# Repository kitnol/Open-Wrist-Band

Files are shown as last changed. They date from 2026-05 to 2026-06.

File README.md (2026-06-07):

# Open-Wrist-Band
Open-wrist-Band it is an open source project which created a wrist band that can measure various physiological parameters. The project features hardware and software deign. Main features:
- Photoplethysmography sensor (PPG)
- Electro Dermal Activity sensor (EDA)
- Internal Measurement Unit sensor (IMU)
- Examples of signal processing  algorithims

## File structure
Project is devided into two folders hardware and software consecutively.  
The hardware folder contains all of the 3D models and PCB design files.  
The software folder contains the scripts for the desktop sofware and ZephyrOS nRF SDK code for the wristband device running on nRF 52833.  
More features and how to get the device set up are described in detail in the individual README.md files within each folder.
## System overview
The system consists of a wearable wristband and a companion desktop application, interconnected via a USB interface
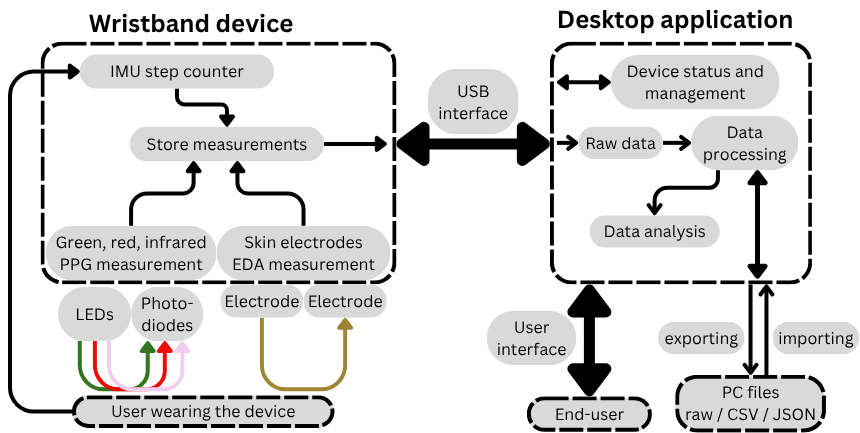
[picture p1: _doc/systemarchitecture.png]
System overview
  
The wristband measures and saves PPG, EDA and steps data in the onboard memory throughout the week, which is then offloaded to the desktop using a USB-C cable. The measurement parameters (frequency, LED brightness...) can be configured within the AS7058 chip driver. The captured data is then parsed and can be analysed using python notebooks.

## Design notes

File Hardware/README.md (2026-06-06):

# Hardware Documentation

## Overview

Here is presented a documentation for hardware, mechanical and electronics parts. Here described hardware manufacturing, assembly process and testing.

## Table of Contents

1. [Specifications](#specifications)
2. [PCB](#pcb)
3. [Mechanical](#mechanical)
4. [Full assembly](#full-assembly)
5. [Testing & Validation](#testing--validation)
6. [Bill of Materials (BOM)](#bill-of-materials-bom)

## Specifications

| Parameter | Value | Notes |
|---|---|---|
| Dimensions | 46.3 x 34 x 16.9 mm| |
| Sensors |PPG, EDA, IMU| For hear rate, SpO2, stress measurements and step counting|
| Weight | 42 grams | Weight with the strap|
| Operating Voltage | 3.6-4.2V | From the battery |
| Current Consumption | 1mA | When PPG and EDA measurements are on |
| Wrist circumference | 150-240 mm | |
| Charging current | 100mA | |
| Battery capacity | 800mA | Smaller battery capacity can be used |

## PCB
### PCB ordering

In this section described ordering process of the PCB manufacturing from JLCPCB.

After uploading gerber zip archive form [`./PCB/Fabrication files/Gerber.zip`](https://github.com/kitnol/Open-Wrist-Band/blob/main/Hardware/PCB/Fabrication%20files/Gerber.zip) There is few key options needed to be selected for PCB to be manufactured correctly.

Necessary options:
- **Layers**: 4
- **PCB Thickness**: 1.6mm
- **Surface Finish**: LeadFree HASL
- **Outer Copper Weight**: 1oz
- **Inner Copper Weight** 0.5oz
- **Via Covering**: Epoxy Filled Capped 
- **Min via hole size/diameter**: 0.15mm/(0.25/0.3mm) 

Recommended options:
- **Product Type**: Medical
- **Electrical Test**: Flying Probe Fully Test

### PCB Assembly

You can choose between two methods for assembling the PCB:

- **Manual Assembly**: Order all components listed in the `BOM.csv` and assemble the board entirely on your own.

- **Partial Assembly by JLCPCB**: Upload both `BOM.csv` and `CPL.csv` to the JLCPCB website for automated assembly.

**Important Note**: Because they are not carried in the standard JLCPCB component library, you must purchase the following parts separately and solder them yourself:

- Flash Memory: IS25WP01GJ

- Power Management IC (PMIC): nPM1304

Depending on the time of order additional components may occasionally be out of stock at JLCPCB, requiring you to source and solder them manually as well.

## Mechanical 

### Enclosure manufacturing

The primary method for fabricating the enclosure is FDM 3D printing.

- **Material Selection**: PETG is the recommended choice, though PLA or any other hypoallergenic (skin-safe) plastic may be used.

- **Post-Processing**: After printing, sand the parts and apply a layer of filler-primer to smooth out the print lines.

**Important Safety Note**: Because this device comes into contact with the body, ensure that all selected plastics, primers, and finishes are non-allergenic and completely skin-safe once fully cured.

### Electrodes

The electrodes can be fabricated using either CNC machining or metal 3D printing, utilizing the 3D model found in `./3d models/Electrode.stl`.

- **Material**: Stainless Steel 316 (SS316) is required.

- **Surface Finish**: Because these electrodes come into direct contact with the skin, they must be polished to a smooth surface finish to prevent irritation.

After fabrication, spot-weld a nickel strip to each electrode (the enclosure features a dedicated cutout to accommodate this). These nickel strips provide a solderable surface, allowing you to connect a wire from the electrodes directly to the PCB.

### PPG window

For the PPG sensor to function correctly, it requires an unobstructed view of the skin while remaining protected from sweat and moisture. To achieve this, fabricate a small protective separator from a **0.5 mm thick sheet of transparent PET plastic or glass**. Installation Steps:
  
- **Cut the Window**: Cut a $11.4 \text{ mm} \times 12.4 \text{ mm}$ rectangle out of the transparent material.
  
- **Apply Adhesive**: Using a toothpick, carefully apply a small amount of superglue along the recessed rim of the enclosure's cutout. 
  **Caution**: Avoid getting any glue near the center of the cutout where it could obscure the LEDs or photodiodes.
  
- **Set the Window**: Place the transparent window into the cutout and apply light, steady finger pressure for 1 to 2 minutes to ensure a secure bond.

## Full assembly

Once all components have been sourced and manufactured, you can proceed with the final assembly.

**Important**: You must flash the firmware onto the MCU using a J-LINK debugger before assembling the hardware. Please refer to the flashing guide located in the [Software](https://github.com/kitnol/Open-Wrist-Band/tree/main/Software) folder before proceeding. Also remove the male pins for J-LINK after programming, future updates can be done via USB.

**Step 1: Install the Electrodes**

1. Gather the fully prepared electrodes (with nickel strips attached), the casing body, and the 3D-printed jig (Glue_support.stl).
   
2. Route the nickel strip through its designated cutout in the casing, apply superglue beneath the electrode, and press it firmly into position.
   
3. Use the Glue_support.stl jig to clamp the casing body and electrode securely in a vice.
   
4. Allow **10–20 minutes** for the glue to fully cure. Repeat this process separately for each electrode.

**Step 2: PCB Mounting & Wiring**

1. Seat the PCB into the casing body.
   
2. Solder lead wires onto the exposed electrode nickel strips.
   
3. Solder the opposite ends of these wires into holes 2 and 4 of the PCB (located on the side opposite the USB port, counting sequentially from the outer edge of the PCB).
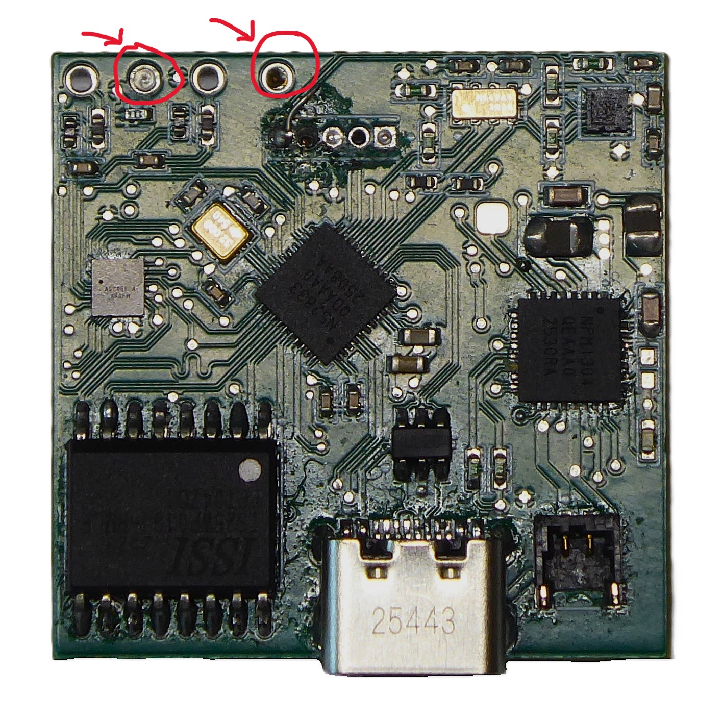
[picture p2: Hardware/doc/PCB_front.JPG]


**Step 3: Battery Installation & Final Closure**

1. Connect the battery, position it neatly on top of the PCB, and place the lid over the casing.

2. Caution: Double-check that no wires are pinched or trapped between the casing body and the lid.
   
3. Secure the enclosure using four M2 x 3mm screws to complete the assembly.

## Testing & Validation

### Hardware Testing
- [ ] Short circuits test
- [ ] Power test
- [ ] Charging test **(TODO)**

#### Short circuits test

Pre-Power Short Circuit Test

Once the PCB is fully assembled, you must test it for short circuits before applying power. Set your multimeter to continuity mode and check the continuity between the following points:

- **GND** and the **1.8V** line

- **GND** and the **2.4V** line

- **1.8V** line and the **2.4V** line

If the multimeter does not beep (indicating no continuity), it is safe to power on the PCB. If continuity is detected, a short circuit exists. <u>Do not apply power until you locate and resolve the source of the short.</u>

#### Power testing

Before programming, power the PCB via USB or battery and use a multimeter to measure the 1.8V and 2.4V lines. If the voltages are correct, it is safe to proceed with programming.

**Troubleshooting Guide:**

- **Voltages are too low**: Check the power input to ensure the board is receiving either 5V (USB) or 3.7V–4.2V (battery).

- **1.8V line is too high**: Immediately disconnect power. Verify that resistor R6 is 47 kΩ. Note that if this line exceeded 1.98V, the AS7058 component is likely damaged and must be replaced.

- **2.4V line is too high**: Power off the PCB immediately and verify that resistor R7 is 47 kΩ. Component damage is unlikely on this line, so no replacements should be necessary once the resistor issue is fixed.

## Bill of Materials (BOM)

### Mechanical BOM

| Part number | Description  | Quantity | Unit Price | Source |
|---|---|---|---|---|
| AM4885 | Li-Pol battery 800mAh, 3.7V, 622540 | 1 |€6.55 | [AM4885](https://ampul.eu/en/battery/6303-li-pol-battery-800mah-37v-622540) |
| ACHLR-02V-S | Battery connector | 1 | €0.13 | [ACHLR-02V-S](https://www.digikey.de/en/products/detail/jst-sales-america-inc/achlr-02v-s/5272191) |
| ASACHLSACHL28W152 | Battery wires | 1 | €0.98 | [ASACHLSACHL28W152](https://www.digikey.de/en/products/detail/jst-sales-america-inc/ASACHLSACHL28W152/8107430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) |
| M2 3mm | Screw for lid | 4 | €5.88 | [M2 3mm](https://dk.rs-online.com/web/p/maskinskruer/9141560) |
| PET 0.5mm | Plastic sheet | 1 | €7.5 | [PET 0.5mm](https://www.amazon.com/Plastic-Clarity-Resistant-Display-Packaging/dp/B0GJ6CKP9T?th=1) |

**Total Cost**: €38.68

### Electronics BOM
| Designator | Description | Footprint | JLCPCB Part | Quantity | Unit price ($) | Total cost ($) |
|---|---|-----|---|---|---|---|
| C1, C3, C4, C5, C6, C8, C10, C16, C21, C22, C32, C33, C34, C35 | 100nF | 0402 | C1525 | 14 | $0.0017 | $0.0238 |
| C2 | 10 µF | 0402 | C15525 | 1 | $0.0178 | $0.0178 |
| C7 | 1 µF | 0402 | C52923 | 1 | $0.0053 | $0.0053 |
| C9, C11, C14, C17, C25 | 1µF 40% 50V | 0603 | C15849 | 3 | $0.0156 | $0.0468 |
| C15, C19, C23, C24, C26 | 10 µF | 0603 | C19702 | 5 | $0.0149 | $0.0745 |
|  | 1 µF | 0603 | C15849 | 2 | $0.0108 | $0.0216 |
| C18 | 2.2 µF | 0603 | C49326366 | 1 | $0.0092 | $0.0184 |
| C20 | 100 pF | 0402 | C1546 | 1 | $0.0014 | $0.0014 |
| C27 | 4.7 µF | 0603 | C19666 | 1 | $0.0138 | $0.0138 |
| C28, C29, C30, C31 | 0.047 µF | 0402 | C82219 | 4 | $0.0024 | $0.0096 |
| C36, C37 | 12 pF | 0402 | C1547 | 2 | $0.0016 | $0.0032 |
| D1, D2 | SFH 7018A | SFH 7018 | C24570310 | 2 | $1.8124 | $3.6248 |
| D3, D4 | Blue LED | 0402 | C22355736 | 1 | $0.0087 | $0.0174 |
| D5, D6, D7, D8 | TVS DIODE | 0402 | C10676 | 4 | $0.0426 | $0.1704 |
| D9, D10, D11, D12 | SFH2705 | DFN175P2 | C6672359 | 4 | $1.7060 | $6.824 |
| J1 | USB-C Molex-2171790001 | SMD | C3197684 | 1 | $0.6895 | $0.6895 |
| J2 | Battery connector BM02B-ACHLKS | FP-BM02B | C594367 | 1 | $0.7975 |$0.7975 |
| J3 | M50-3530542 | Plugin,P=1.27mm| C6293302 | 1 | $0.3278 | $0.3278 |
| L1, L2 | CIGT201610LH2R2MNE | 0806 | C307626 | 2 | $0.1070 | $0.214 |
| R1, R2, R12, R13 | 5.1K | 0402 | C25905 | 4 | $0.0009 | $0.0036 |
| R3, R4, R5, R8, R11, R14, R19, R20, R21, R22, R23, R24, R25 | 10K | 0402 | C844452 | 17 | $0.0013 | $0.0221 |
| R6, R7 | 47K | 0402 | C25792 | 2 | $0.001 | $0.002 |
| R9, R10, R16, R17 | 100K | 0402 | C25741 | 4 | $0.0009 | $0.0036 | 
| R15, R26, R27, R28 | 4.7K | 0402 | C25900 | 4 | $0.001 | $0.004  |
| R18 | 1K | 0402 | C11702 | 1 | $0.001 | $0.001 |
| U1 | LIS2DS12TR | LGA-12(2x2) | C915682 | 1 | $2.0411 | $2.0411 |
| U2 | nRF52833 | QFN40_5X5 | C3007767 | 1 | $5.0552 | $5.0552 |
| U3 | NPM1304 | QFN32 | C49449665 | 1 | $4.3002 | $4.3002 | 
| U4 | RV-3028-C7 | FP-RV-3028-C7 | C3019759 | 1 | $2.2667 | $2.2667 |
| U5 | AS7058 | WLCSP-42(2.8x2.6) | C23782775 | 1 | $7.5763 | $7.5763 |
| U6 | IS25WP01GJ-RMLE-TY (128MB) | 16-SOIC | [DigiKey](https://www.digikey.de/en/products/detail/issi-integrated-silicon-solution-inc/IS25WP01GJ-RMLE-TY/29286651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) | 1 | $14.38360 | $14.38360 |
| U7 | USBLC6-2SC6 (ESD) | SOT-23-6 | C2827654 | 1 | $0.0410 | $0.0410 |
| Y1 | XYDCELNANF-32M | SMD2520-4P | C124330 | 1 | $0.3137 | $0.3137 |

**Total Cost**: $48.8926

---

**Last Updated**: 06-06-2026

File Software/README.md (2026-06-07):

## Folder structure
The code is split into two subfolders, embedded software and desktop software. The desktop software is written using python whereas the embedded software is written with C using ZephyrOS RTOS implementation.
## Device communication
The communication betweend the PC and the embedded device happens with UART over USB (USB CDC ACM) using ZephyrOS shell implementation. Custom commands are predefined in the embedded code to allow the desktop app to interface and configure the device. The connection happens in master-slave configuration where the PC (master) sends the commands and the device (slave) responds to the commands.
> **Table:** Defined commands for the interface, commands marked with (dbg) are meant for debugging only.

| Cmd | Subcommand | Behavior of MCU | Behavior of application |
| --- | --- | --- | --- |
| `rtc` | `get` | Send current RTC time to the application | Check if device time is correct, sync if it is not and warn user |
| `rtc` | `set y.m.d h:m:s` | Set received time from application to RTC | Send system time to MCU, tell user if time was set correctly |
| `as7058` | `start` | Start measuring data | Show device as measuring |
| `as7058` | `stop` | Stop measuring data | Show device as not measuring |
| `as7058` | `read` | Transmit current FIFO buffer to the app | (dbg) Show incoming FIFO bytes |
| `flash` | `ls` | List files | (dbg) Show files in the folder |
| `flash` | `info <path>` | Send file info at path | Asks for readings.bin, shows how much measured data there is |
| `flash` | `dump <path>` | Transmit raw binary data (bytes) of the file | Receive transmitted binary data and save them |
| `flash` | `hex <path>` | Send hex dump of the file | (dbg) Used to inspect files |
| `flash` | `rm <path>` | Delete the file at path | Triggered by clearing current measurements from device, tells user if completed |
| `config` | `getid` | Send configured ID | Show ID of the device |
| `config` | `setid <id>` | Set device ID to the received ID | User sets the ID, shows updated ID |
| `config` | `get` | Send current config on device | Show device config in UI |
| `config` | `set <bytes>` | Receive config and save it to memory | Set device config based on how the user cofigured it in UI config |
| `<any>`  | `<any>` | (dbg) Do action of the built-in command| (dbg) Send any of the built-in zephyros shell commands

### Connection
Upon connection the device opens two COM ports to the PC, one meant for the shell interface and the other one meant for the binary data flash dumps. Because the desktop application itself is currently not developed, separate standalone scripts are used for recieving the data dumps, while the shell interface is used manually by the user using a serial terminal e.g. AuTerm to configure the device and initiate the transfers.

## Setting up device to take measurements (Manually using shell)
To setup measurements after the device is successfully flashed we need to tell it to start measuring. This functionality remains to be implemented in the user interface to simplify the process.
#### Connecting the device
1. Open a serial terminal application (AuTerm is used in this case, but we can use any other) 
2. Connect the device using USB-C cable and find the COM ports corresponding to the device, there should be two new COM ports showing up. The ports will have random numbers as they are assigned by the PC.  
Ports showing up
3. Open one of the ports to the device, if nothing shows up it is the data transfer port. Close it and open the other port where the shell interface should show up.  
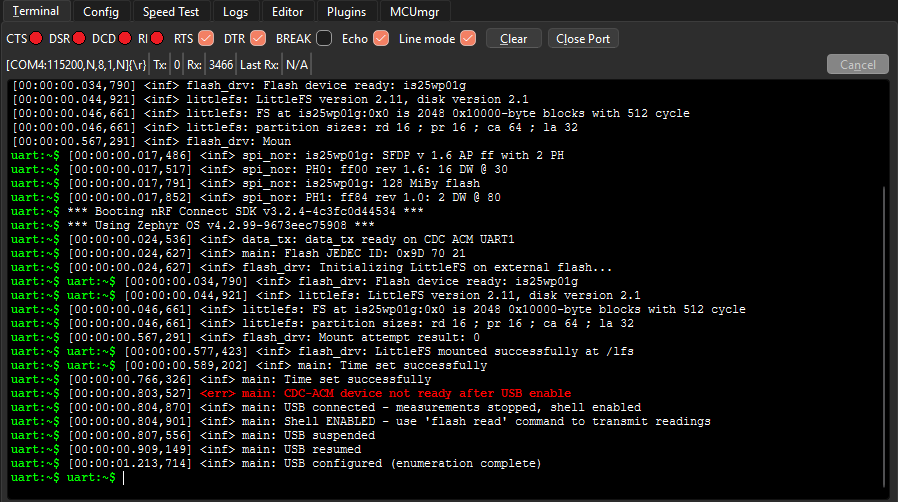
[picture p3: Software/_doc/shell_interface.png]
Shell interface

#### Starting measurement
4. We can see the onboard files using command `flash ls`. If we want to delete previous measurements so they do not mix up, we can use `flash rm /lfs/readings.bin`. Otherwise the measurements get appended at the end of the file
5. To start the measurement we send `as7058 start`. Depending on the measurement configuration we should start seeing LEDs blinking on the bottom of the device.  
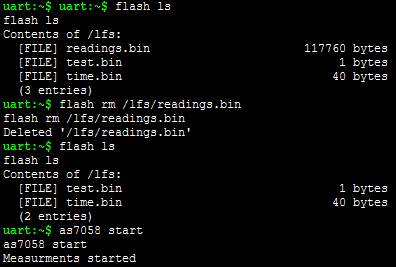
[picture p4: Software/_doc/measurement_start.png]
Starting measurement

6. In case we want to read the AS7058's FIFO memory while the measurements are running we can use `as7058 read` which will dump the current FIFO readings into the shell interface, instead of saving them into readings.bin. The device then continues taking measurements normally and would save the next FIFO memory measurements into the readings.bin file when the FIFO threshold is reached. It is important to note that this should be used for debugging only as it can create discontinuities in the readings.bin file.
## Stopping measurements and offloading the data (Manually using shell + scripts)
We begin with the same steps for connecting the device as previously.
### Stopping measurement
4. We stop the measurements by sending `as7058 stop`
5. We can see the size of collected measuremnts by doing `flash ls` where it shows the number of bytes  
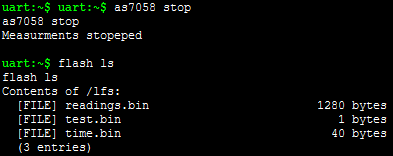
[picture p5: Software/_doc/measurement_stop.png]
Stopping measurement

### Offloading data
6. We initiate the offloading by sending shell command `flash dump /lfs/readings.bin` Then either by using a second serial terminal or by using the script data_receive.py we can capture the incomming transmission. The transmission is blocking so the data will wait for the port to be opened and won't be lost if we initiate the transmission without having the second port open first. From the command we can see the number of packets and number of bytes of the incoming transmission.  

#### Using second serial terminal
7. We initiate the connection on the second COM port shown by the device. We can see the incoming data captured in the terminal. If possible we can then export the data from the terminal.  
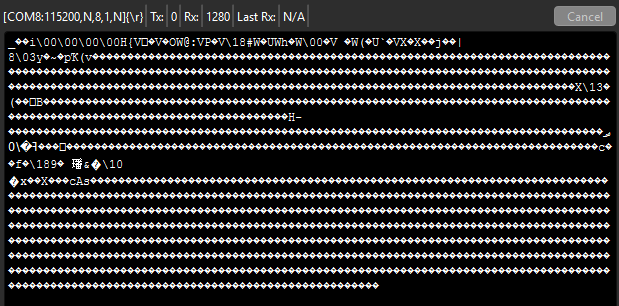
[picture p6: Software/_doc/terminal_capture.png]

#### Using the data_receive.py script
7. We open the receiving script. Modify the number of packets based on the output of the flash dump command and change the COM port to the second COM port of the device. We can also modify the desired file name.  
Receiving script
8. We can see the transmission happening and the data being saved in the .bin file.  
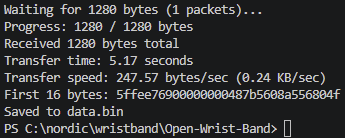
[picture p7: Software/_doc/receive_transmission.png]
Received transission


## To be implemented:
This is how it was envisioned that the device-application connection would interact, with a flowchart describing the behavior upon USB connection. This remains to be implemented from the desktop application side.

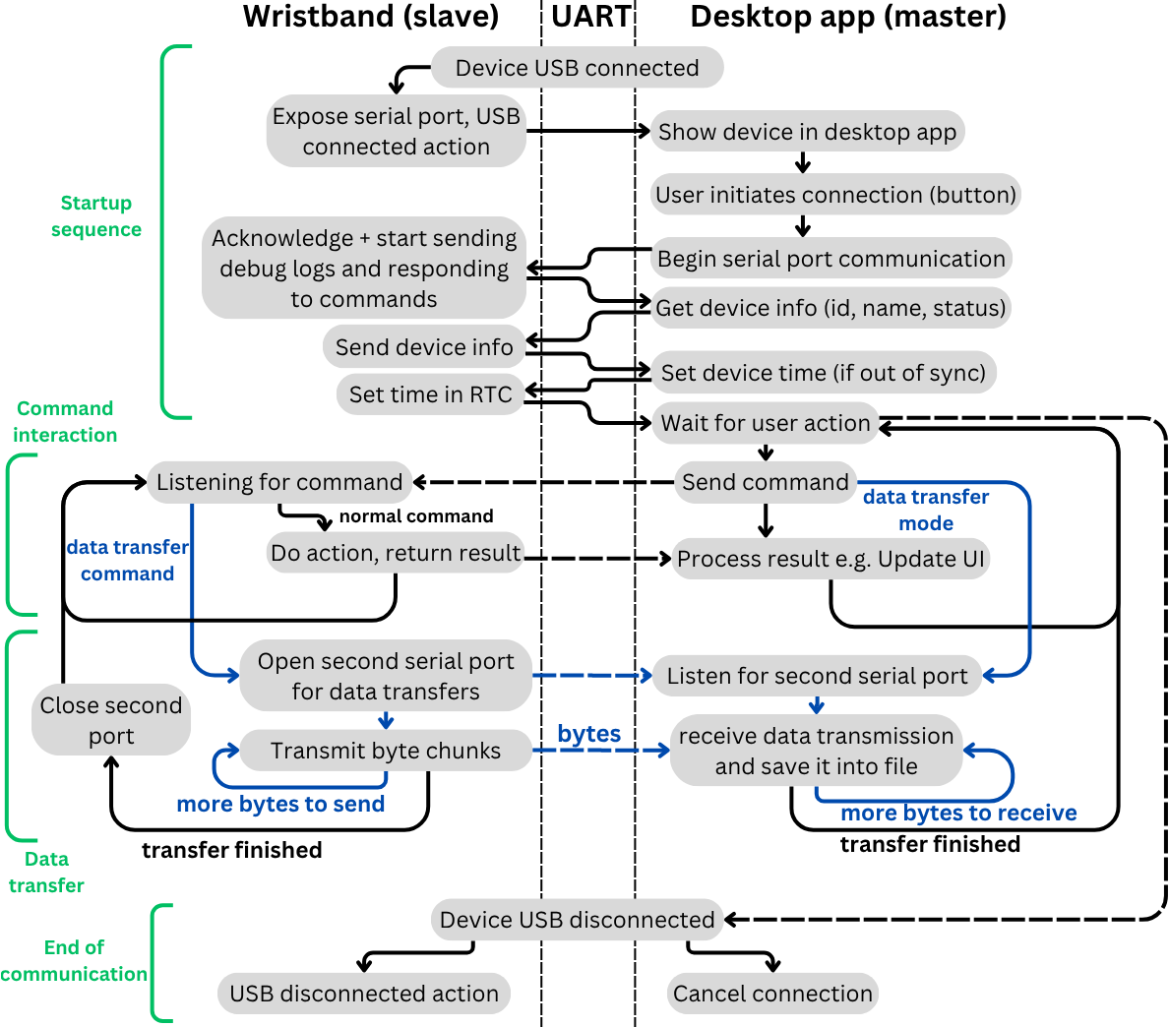
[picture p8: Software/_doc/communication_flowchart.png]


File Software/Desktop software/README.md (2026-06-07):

# Desktop software
### Files:
- `Analysing_Green_LED_data.ipynb` - Python notebook with example code for analysing gathered green led measurements for BPM calculation
- `Analysing_Red_IR_LED_data.ipynb` - Python notebook with example code for analysing gathered red and infrared led measurements for blood oxygen calculation
- `data_recieve.py` - Example code for receiving byte chunks and saving them in raw binary file. The script needs to have correct number of receiving byte chunks set and correct COM port set. Example of one FIFO reading (one byte chunk)   
  byte chunk
- `data_parse.py` - Example code for parsing byte chunks and the markers and ADC values within it. *TODO: sorting measurements by markers and exporting to different files*  
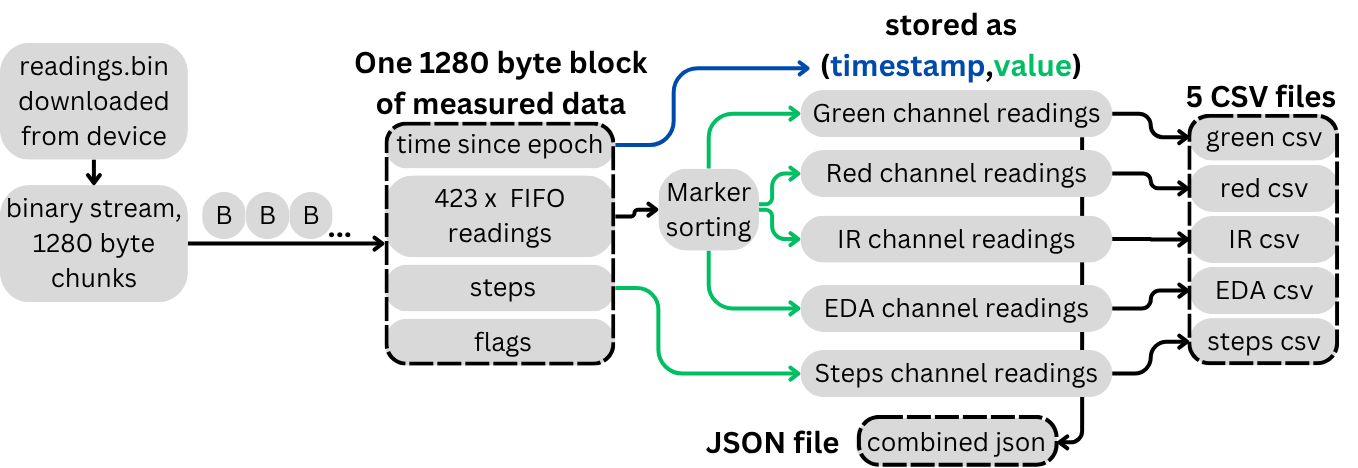
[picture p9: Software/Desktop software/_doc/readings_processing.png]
Binary file parsing
  
- `m_green.csv` - Example data captured by photodiodes of green LED shining
- `m_red_IR.csv` - Example data captured by photodiodes of red and IR LED shining, alternating every other measurement starting with IR being first line

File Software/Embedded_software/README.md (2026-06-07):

# Embedded software
### Project files structure:
- `boards/` - custom board import into Zephyr OS based on the PCB design and required features, contains pin mapping definitions and enables individual subsystems (I2C, SPI, USB, UART)
- `src/` - all of the source code that is part of the embedded application
  - `main.c` - main code setup
  - `as7058_drv.c` - custom made driver for AS7058 bio chip based on its datasheet
  - `flash_drv.c` - flash layer for the onboard spi nor flash - littlefs implementation
  - `shell.c` - the implementation of shell commnads
  - `usb_drv.c` - the implementation of the usb interface management
- `sysbuild/` - mcuboot bootloader implementation and configuration
- `app.overlay` - configuration of specifc components present on the board
- `prj.conf` - project configuration enabling and configuring different zephyros features

Step-by-step guide on how to set up coding environment for embedded software development. The firmware was developed using nRF connect SDK v3.2.4 with nRF extensions enabled, using Visual studio code.

## Environment setup
1. Download Nordic semiconductor SDK for nrf52833 in Visual studio code
2. Open/import the project folder from github
3. Go into your SDK installation ncs\v3.2.4\bootloader\mcuboot\zephyr\main.c and implement https://github.com/mcu-tools/mcuboot/pull/1903 
This feature was added to allow entering DFU mode (for code flashing) after triggering a hardware reset, instead of entering DFU mode on every single after power-up. This improves power usage by not wasting time in DFU mode when not needed, while keeping the feature to allow for reflashing with non-functional software without a J-link debugger.

## Flashing of an empty board
1. (if needed) Create the build configuration, ensure sysbuild is enabled and the board target is correctly selected. Keep all of the settings on default.  
Create build configuration  
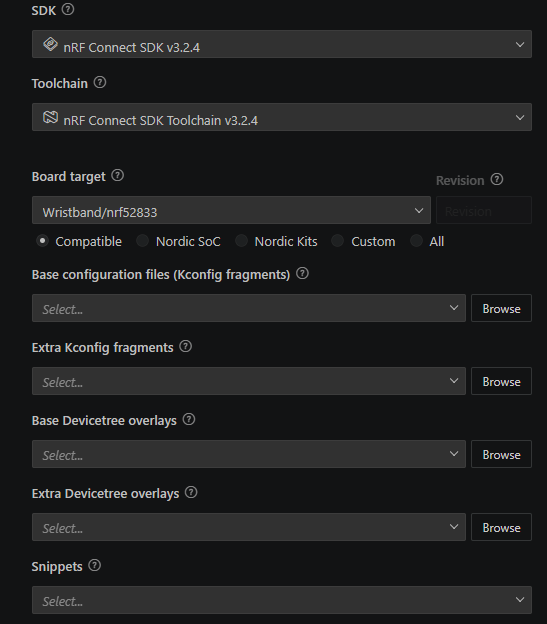
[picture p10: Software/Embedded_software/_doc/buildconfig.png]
Build configration

2. Build the project using nRF Connect SDK actions (or by *west build*)  
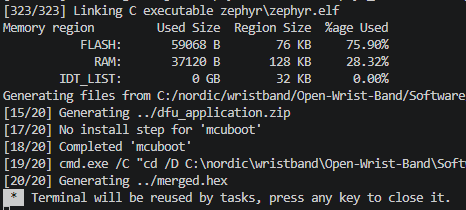
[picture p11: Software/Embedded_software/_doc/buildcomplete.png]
Build complete

3. **IMPORTANT** - Ensure the Segger J-link device is set to **1.8V voltage level** as higher voltages will damage some of the PCB components
4. Connect the Segger J-link to the board using the pin interface, ensure that the "detect pin" on the Segger J-link device is pulled to ground, if needed, as the PCB itself supports only 5 pin J-link interface and does not interact with the "detect pin".
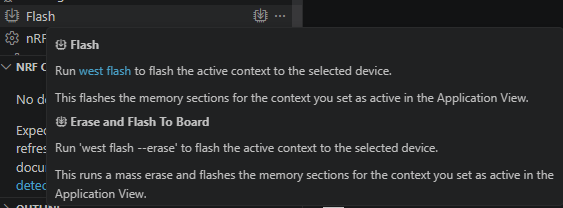
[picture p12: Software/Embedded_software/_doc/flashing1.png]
Build flashing
5. Flash the entire build (sysbuild) onto the nRF microcontroller using built in nRF Connect SDK actions (or by *west flash*)

## Flashing of a board with MCUboot present on it
Prerequisite: Download and open AuTerm as mentioned in course https://academy.nordicsemi.com/courses/nrf-connect-sdk-intermediate/ within Lesson 9 - Bootloaders and DFU 
1. Build the project using nRF Connect SDK actions (or by *west build*)
2. Locate the file in ``build/<folder_name>/zephyr/zephyr.signed.bin`` and open it in AuTerm's MCUmgr
3. Connect the board using USB
4. Press the reset button on the board (if present) or short the reset pin of J-link interface to the ground on the board. (TODO: implement command in shell interface to trigger DFU mode)
5. Find the device in AuTerm and open communication with it
6. Flash using the MCUmgr section  
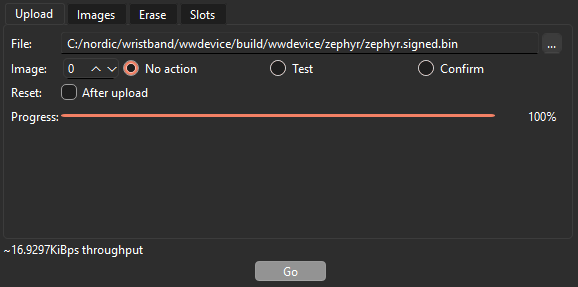
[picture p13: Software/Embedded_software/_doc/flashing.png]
Flashing


## Configurnig measurement parameters using AS7058 Sensor Driver
### Overview
This driver provides initialization and control for the AMS AS7058 multi-parameter biosensor used for PPG (photoplethysmography), ECG, and BioZ measurements. The sensor communicates via I2C and supports configurable LED modulation, photodiode selection, and FIFO-based data acquisition.

### Configuration

The driver uses preprocessor macros for configuration (defined in `as7058_drv.c`):

#### Measurement Sampling
- `PPG_FREQ`: PPG sampling frequency in Hz (default: 10 Hz)
- `ECG_FREQ`: ECG sampling frequency in Hz (default: 10 Hz)
- `FIFO_SAMPLE_COUNT`: Number of samples to buffer before FIFO threshold interrupt (default: 423, max: 511) This should be coordinated together with the byte structure that stores the offloaded data from FIFO

#### LED Configuration
- `PPG_MOD_1`, `PPG_MOD_2`: Enable/disable PPG modulators 1 and 2
- `LED_x_max_current`: Max current setting per LED (0-3, corresponding to 25mA, 150mA, 225mA, or 300mA)
- `LED_x_current`: Actual LED current in mA

**PCB LED Mapping:**
- LED1: IR_1, LED2: GREEN_1, LED3: IR_2
- LED5: RED_2, LED6: GREEN_2, LED7: RED_1

#### Photodiode Selection
- `LED_SUBx`: Configure which LEDs are active for measurement sub-sample x
- `PPG1_PDSELx`, `PPG2_PDSELx`: Configure which photodiodes are active for each sub-sample

Each register uses bit-field encoding:
- `LED_SUB` bits 0-3: Driver1 LED selection, bits 4-7: Driver2 LED selection
- `PDSEL` bits 0-7: Photodiode 1-8 enable/disable  

#### NOTE: For more detailed configuration please consult with the datasheet of AS7058 sensor available online, where all of the registers and their function/configuration is described in detail.

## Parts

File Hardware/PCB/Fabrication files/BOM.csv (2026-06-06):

Comment | Designator | Description | Footprint | LCSC Part
0.1 uF | C1, C3, C4, C5, C6, C8, C10, C16, C21, C22, C32, C33, C34, C35 | CAP CER 100NF 10V X7R 0402 | CAP 0402_1005 | C1525
10 uF | C2 | CAP CER 10UF 10V X5R 0402 | CAP 0402_1005 | C15525
1 uF | C7 | CAP CER 1UF 10V X5R 0402 | CAP 0402_1005 | C52923
1uF +/-40% 50V | C9, C11, C14, C17, C25 | Chip Capacitor, 1µF +/-40%, 50V, 0603, Thickness 1 mm | CAPC0603(1608)100_L | C15849
10 uF | C15, C19, C23, C24, C26 | CAP CER 10UF 16V X5R 0603 | MURATA GRT188 0603_1608 | C19702
2.2 uF | C18 | CAP CER 2.2UF 10V X5R 0603 | CAP 0603_1608 | C49326366
100pF | C20 | CAP CER 100PF 25V NP0 0402 | CAP 0402_1005 | C1546
4.7 uF | C27 | CAP CER 4.7UF 10V X7S 0603 | MURATA GRM188 0603_1608 | C19666
0.047 uF | C28, C29, C30, C31 | CAP CER 0402 47NF 25V X7R 10% | CAP 0402_1005 | C82219
12 pF | C36, C37 | CAP CER 12PF 50V C0G/NP0 0402 | CAP 0402_1005 | C1547
SFH 7018A | D1, D2 | Led, Hr/ir/tg, 655/940/532NM, 120DEG Rohs Compliant: Yes | SFH 7018A-Footprint-1 | C24570310
LED Blue | D3, D4 | LED GREEN CLEAR 0402 SMD | LED 0402_1005 GREEN | C22355736
PGB1010402KR | D5, D6, D7, D8 | TVS DIODE 12V 250V 0402 | FP-PGB1-0402-MFG | C10676
SFH2705 | D9, D10, D11, D12 | Photodiode with wide range of wavelength | DFN175P215X60-2N | C6672359
217179-0001 | J1 | CONN RCP USB2.0 TYP C 24P SMD RA | FP-2171790001-MFG | C3197684
BM02B-ACHLKS-GAN-ETF(LF)(SN) | J2 | CONN HEADER SMD R/A 2POS 1.2MM | FP-BM02B-ACHLKS-GAN-ETF_L-MFG | C594367
M50-3530542 | J3 | 1.27mm (0.05) Pitch SIL Vertical Throughboard Pin Header, selective gold + tin, 5 contacts | HARWIN_M50-3530542 | C6293302
CIGT201610EH2R2MNE | L1, L2 | Description | IND_CIGT2016_SAM | C307626
5.1 kOhms | R1, R2, R12, R13 | RES 5.1K OHM 1% 1/4W 0402 | RES 0402_1005 | C25905
10 kOhms | R3, R4, R5, R8, R11, R14, R19, R20, R21, R22, R23, R24, R25 | RES 10K OHM 0.1% 1/10W 0402 | RES 0402_1005 | C844452
47 kOhms | R6, R7 | RES 47K OHM 1% 1/16W 0402 | RES 0402_1005 | C25792
100 kOhms | R9, R10, R16, R17 | RES 100K OHM 1% 1/5W 0402 | YAGEO RES 0402_1005 | C25741
4.7 kOhms | R15, R26, R27, R28 | RES SMD 4.7K OHM 1% 1/16W 0402 | YAGEO RES 0402_1005 | C25900
1 kOhms | R18 | RES SMD 1K OHM 5% 1/16W 0402 | YAGEO RES 0402_1005 | C11702
Switch | SW1
LIS2DS12TR | U1 | ACCEL 2-16G I2C/SPI 12LGA | FP-LGA12_8566956-MFG | C915682
NRF52833-QDAA-R7 | U2 | Description | QFN40_5X5_DQ_NOR | C3007767
NPM1304-QEAA-R7 | U3 | NPM1304 POWER MANAGEMENT IC | QFN50P500X500X90-33N | C49449665
RV-3028-C7 32.768kHz 1ppm TA QC | U4 | Real Time Clock Serial 2byte Clock/Calendar/Alarm/Timer/Battery Backup 8-Pin CSMD T/R | FP-RV-3028-C7_32_768kHz_1-MFG | C3019759
AS7058-BWLM | U5 | AS7058 Series 1.8 V PPG/ECG/BioZ/EDA Vital Sign Monitoring IC - WLCSP-42 | BGA42C40P6X7_254X282X60 | C23782775
IS25WP01GJ-RMLE-TY | U6 | Flash Memory, Serial NOR, 1 Gbit, 128M x 8bit, QPI, SPI, SOIC, 16 Pins | SOIC127P1030X265-16N
USBLC6-2SC6 | U7 | 5A 17V 6V Unidirectional 5.25V SOT-23-6 ESD and Surge Protection (TVS/ESD) ROHS | STM-SOT23-6L_V | C2827654
32MHz | Y1 | CRYSTAL 32.0000MHZ 8PF SMD | ABRACON ABM10 | C124330

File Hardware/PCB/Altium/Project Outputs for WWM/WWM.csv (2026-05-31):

Comment | Designator | Description | Footprint | LCSC Part
0.1 µF | C1, C3, C4, C5, C6, C8, C10, C16, C21, C22, C32, C33, C34, C35 | CAP CER 100NF 10V X7R 0402 | CAP 0402_1005 | C527001
10 µF | C2 | CAP CER 10UF 10V X5R 0402 | CAP 0402_1005 | C5272370
1 µF | C7 | CAP CER 1UF 10V X5R 0402 | CAP 0402_1005 | C106254
Capacitor 1µF +/-40% 50V 0603 | C9, C11, C14 | Chip Capacitor, 1µF +/-40%, 50V, 0603, Thickness 1 mm | CAPC0603(1608)100_L | C15849
10 µF | C15, C19, C23, C24, C26 | CAP CER 10UF 16V X5R 0603 | MURATA GRT188 0603_1608 | C2936601
1µF | C17, C25 | CAP CER 1UF 25V X5R 0603, CAP CER 1UF 10V X5R 0603 | CAP 0603_1608 | C15849
2.2 µF | C18 | CAP CER 2.2UF 10V X5R 0603 | CAP 0603_1608 | C49326368
100pF | C20 | CAP CER 100PF 25V NP0 0402 | CAP 0402_1005 | C541358
4.7 µF | C27 | CAP CER 4.7UF 10V X7S 0603 | MURATA GRM188 0603_1608 | C342959
0.047 µF | C28, C29, C30, C31 | CAP CER 0402 47NF 25V X7R 10% | CAP 0402_1005 | C107020
12 pF | C36, C37 | CAP CER 12PF 50V C0G/NP0 0402 | CAP 0402_1005 | C18220923
SFH 7018A | D1, D2 | Led, Hr/ir/tg, 655/940/532NM, 120DEG Rohs Compliant: Yes | SFH 7018A-Footprint-1 | C28598189
Blue | D3 | LED GREEN CLEAR 0402 SMD | LED 0402_1005 GREEN
Green | D4 | LED GREEN CLEAR 0402 SMD | LED 0402_1005 GREEN
PGB1010402KR | D5, D6, D7, D8 | TVS DIODE 12V 250V 0402 | FP-PGB1-0402-MFG | C10676
SFH2705 | D9, D10, D11, D12 | Photodiode with wide range of wavelength | DFN175P215X60-2N | C6672359
217179-0001 | J1 | CONN RCP USB2.0 TYP C 24P SMD RA | FP-2171790001-MFG | C3197684
BM02B-ACHLKS-GAN-ETF(LF)(SN) | J2 | CONN HEADER SMD R/A 2POS 1.2MM | FP-BM02B-ACHLKS-GAN-ETF_L-MFG | C594367
M50-3530542 | J3 | 1.27mm (0.05) Pitch SIL Vertical Throughboard Pin Header, selective gold + tin, 5 contacts | HARWIN_M50-3530542 | C6293302
CIGT201610EH2R2MNE | L1, L2 | Description | IND_CIGT2016_SAM
5.1 kOhms | R1, R2, R12, R13 | RES 5.1K OHM 1% 1/4W 0402 | RES 0402_1005 | C25905
10 kOhms | R3, R4, R5, R8, R11, R14, R19, R20, R21, R22, R23, R24, R25 | RES 10K OHM 0.1% 1/10W 0402 | RES 0402_1005 | C844452
47 kOhms | R6, R7 | RES 47K OHM 1% 1/16W 0402 | RES 0402_1005 | C25792
100 kOhms | R9, R10, R16, R17 | RES 100K OHM 1% 1/5W 0402 | YAGEO RES 0402_1005 | C313329
4.7 kOhms | R15, R26, R27, R28 | RES SMD 4.7K OHM 1% 1/16W 0402 | YAGEO RES 0402_1005 | C881369
1 kOhms | R18 | RES SMD 1K OHM 5% 1/16W 0402 | YAGEO RES 0402_1005 | C176101
C913778 | SW1 | Tactile Switch, SPST-NO, 50 mA, 12 V, 4-Pin SMD, RoHS, Tape and Reel | ESWI-TL3342F160QG_V | C913778
LIS2DS12TR | U1 | ACCEL 2-16G I2C/SPI 12LGA | FP-LGA12_8566956-MFG | C915682
NRF52833-QDAA-R7 | U2 | Description | QFN40_5X5_DQ_NOR | C3007767
NPM1304-QEAA-R7 | U3 | NPM1304 POWER MANAGEMENT IC | QFN50P500X500X90-33N
RV-3028-C7 32.768kHz 1ppm TA QC | U4 | Real Time Clock Serial 2byte Clock/Calendar/Alarm/Timer/Battery Backup 8-Pin CSMD T/R | FP-RV-3028-C7_32_768kHz_1-MFG | C3019759
AS7058-BWLM | U5 | AS7058 Series 1.8 V PPG/ECG/BioZ/EDA Vital Sign Monitoring IC - WLCSP-42 | BGA42C40P6X7_254X282X60 | C23782775
IS25WP01GJ-RMLE-TY | U6 | Flash Memory, Serial NOR, 1 Gbit, 128M x 8bit, QPI, SPI, SOIC, 16 Pins | SOIC127P1030X265-16N | C7519
USBLC6-2SC6 | U7 | 5A 17V 6V Unidirectional 5.25V SOT-23-6 ESD and Surge Protection (TVS/ESD) ROHS | STM-SOT23-6L_V | C3197684
32MHz | Y1 | CRYSTAL 32.0000MHZ 8PF SMD | ABRACON ABM10 | C124330

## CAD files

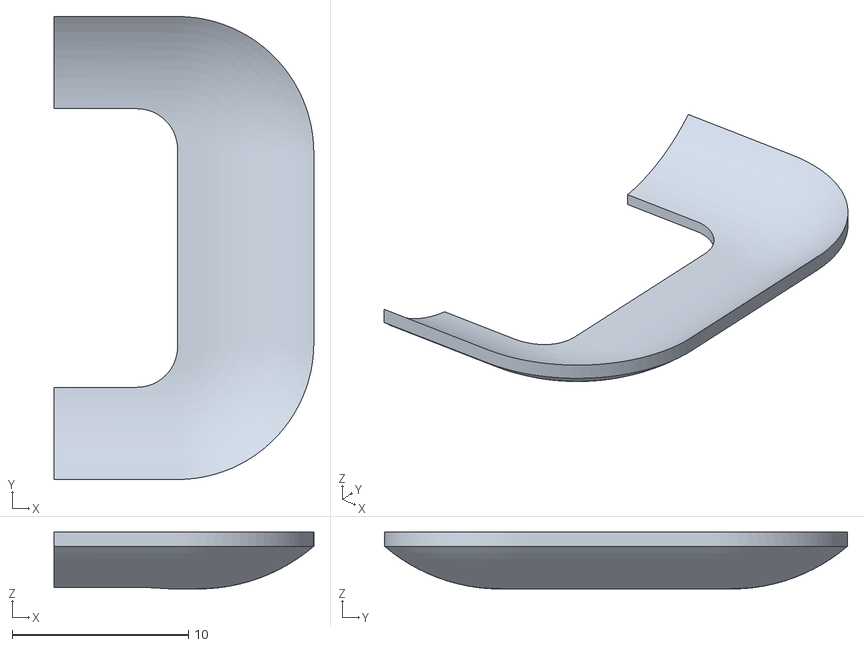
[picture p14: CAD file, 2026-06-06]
Hardware/3d models/Electrode.stl
14.7 x 26.3 x 3.23

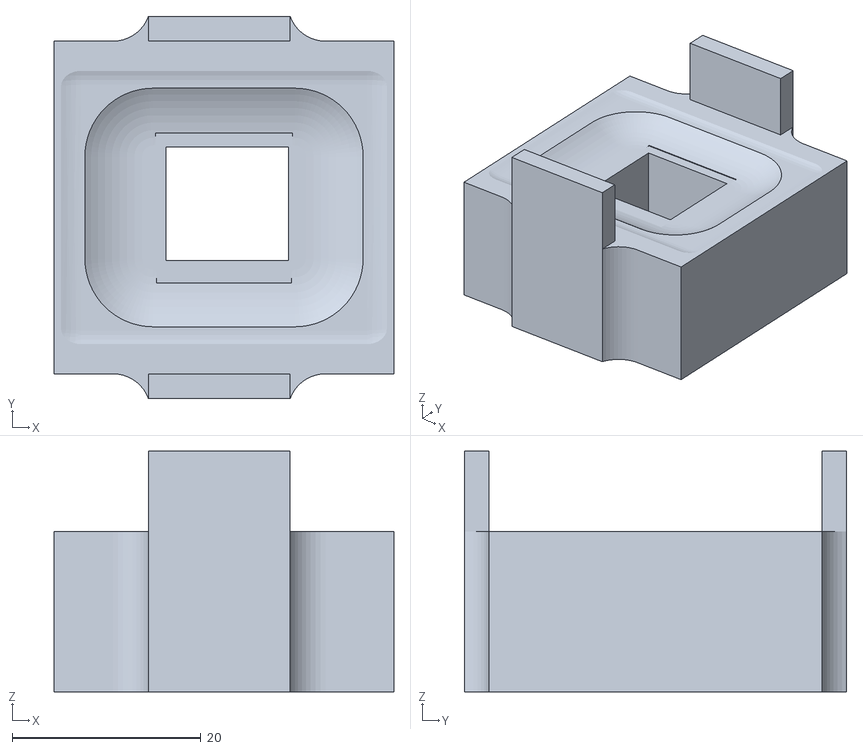
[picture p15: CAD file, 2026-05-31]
Hardware/3d models/Glue_Support.stl
36.0 x 40.5 x 25.5

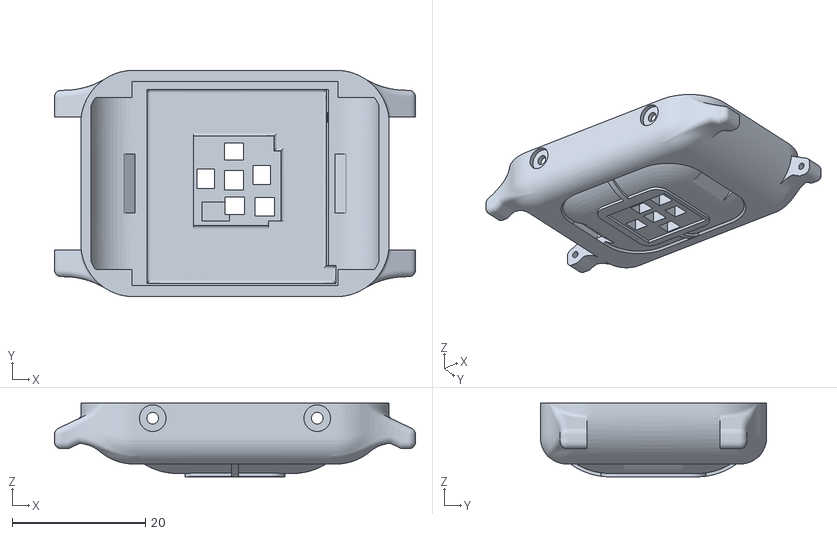
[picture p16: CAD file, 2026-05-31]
Hardware/3d models/Case_Body.stl
54.2 x 34.0 x 11.1

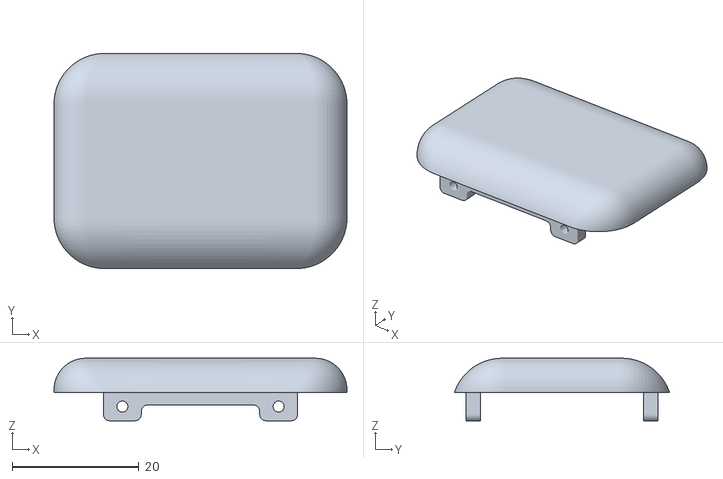
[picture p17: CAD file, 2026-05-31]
Hardware/3d models/Case_Lid.stl
46.3 x 34.0 x 9.90

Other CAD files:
Hardware/3d models/Case_Body.obj
Hardware/3d models/Case_Lid.obj
Hardware/3d models/Electrode.obj
Hardware/3d models/Glue_Support.obj

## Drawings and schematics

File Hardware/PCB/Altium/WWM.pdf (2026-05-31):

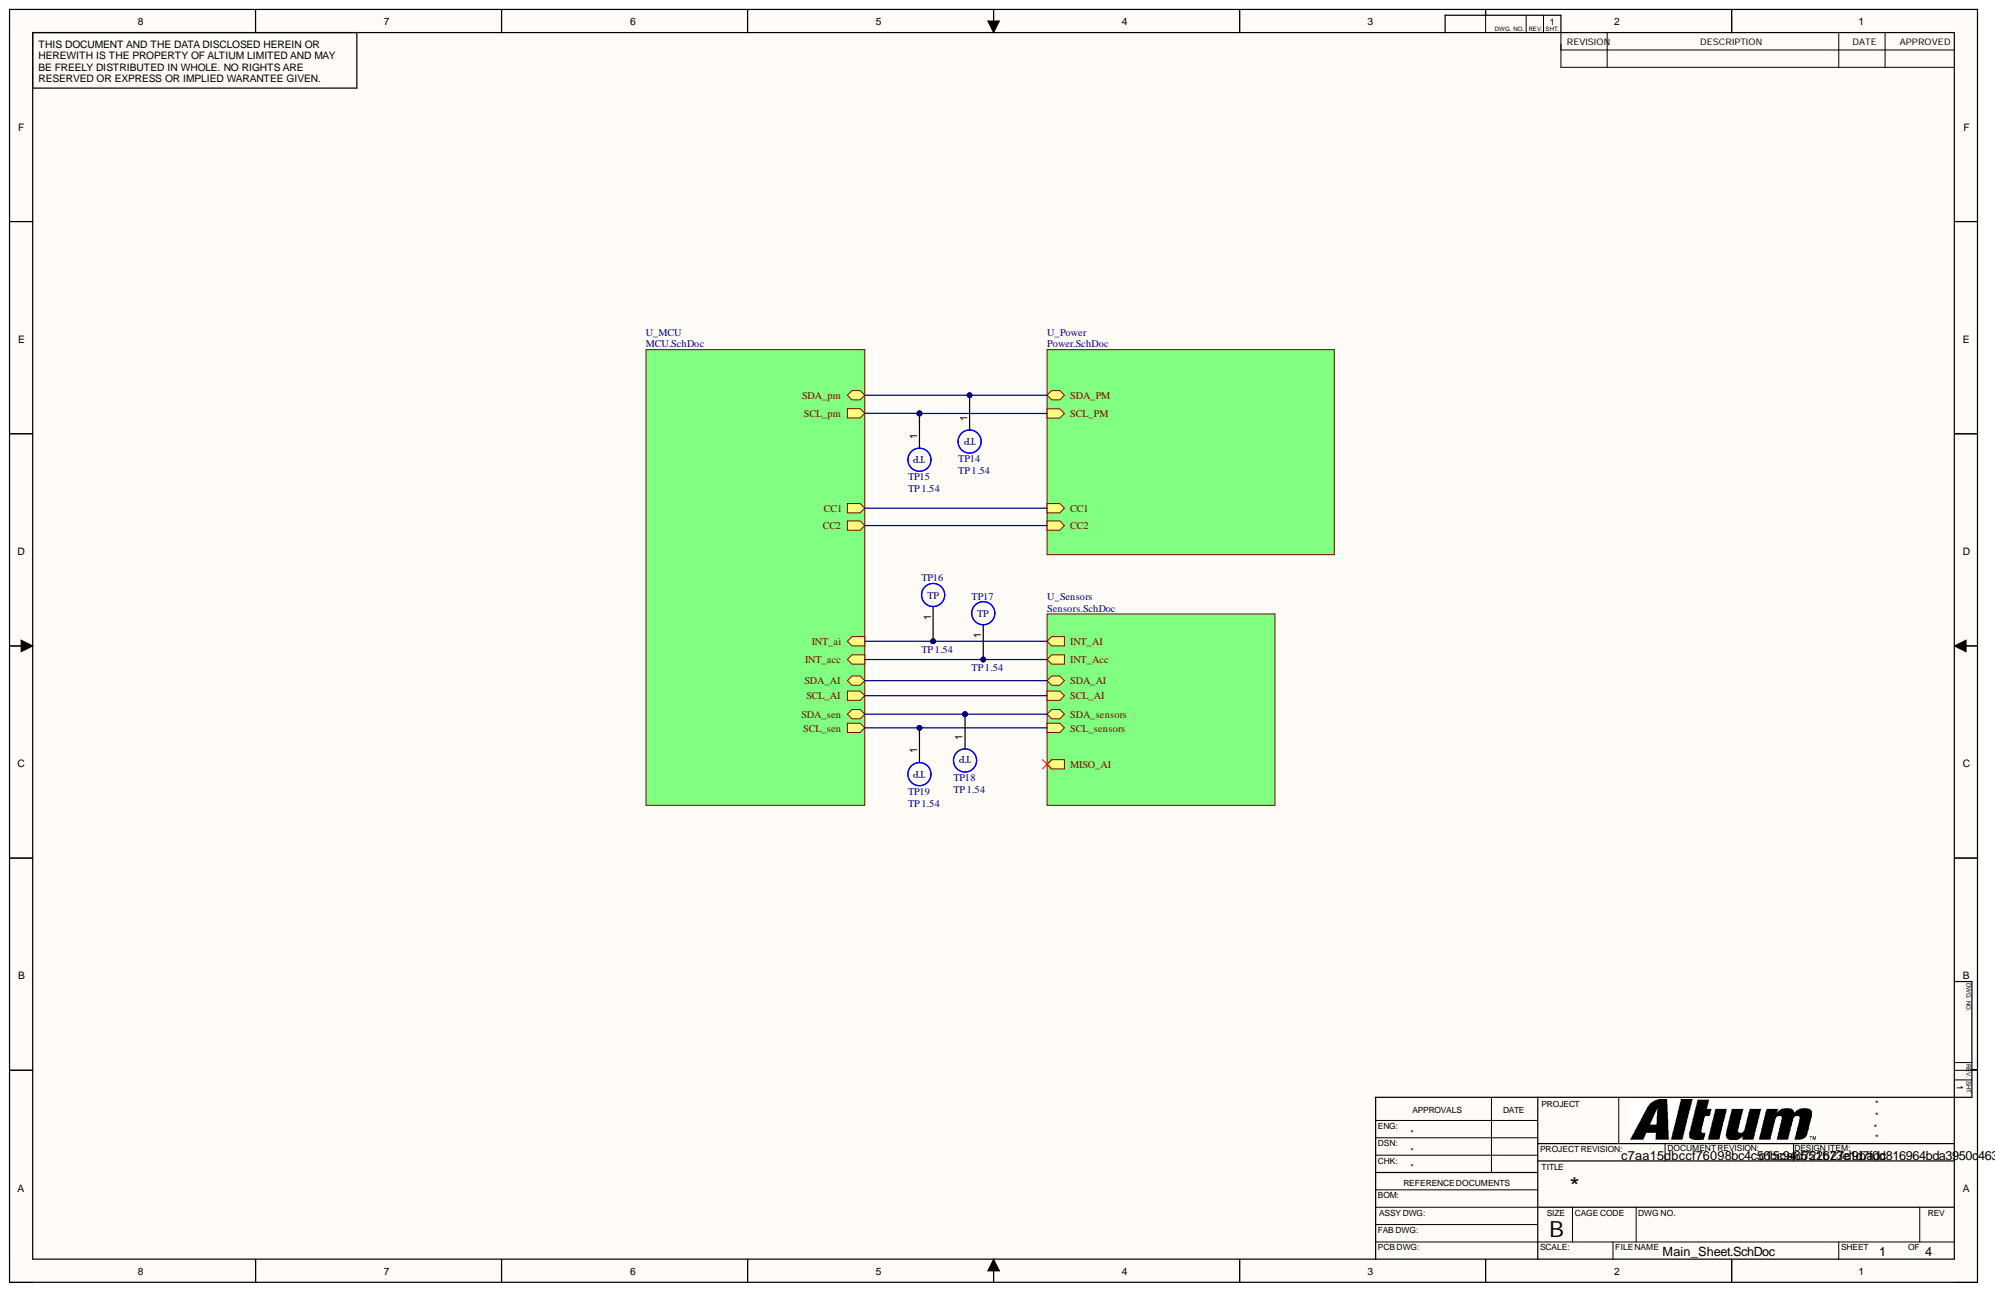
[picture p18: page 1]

8 | 7 | 6 | 5 | 4 | 3 | DWG. NO. | REV. | 1 SHT. | 2 | 1

THIS DOCUMENT AND THE DATA DISCLOSED HEREIN OR HEREWITH IS THE PROPERTY OF ALTIUM LIMITED AND MAY BE FREELY DISTRIBUTED IN WHOLE. NO RIGHTS ARE RESERVED OR EXPRESS OR IMPLIED WARANTEE GIVEN. | U_MCU U_Power MCU.SchDoc Power.SchDoc | REVISION | DESCRIPTION | DATE | APPROVED

REV. SHT. DWG. NO.

DATE | PROJECT | * * APPROVALS * *

ENG: *
CHK: * | | TITLE *

DSN: *

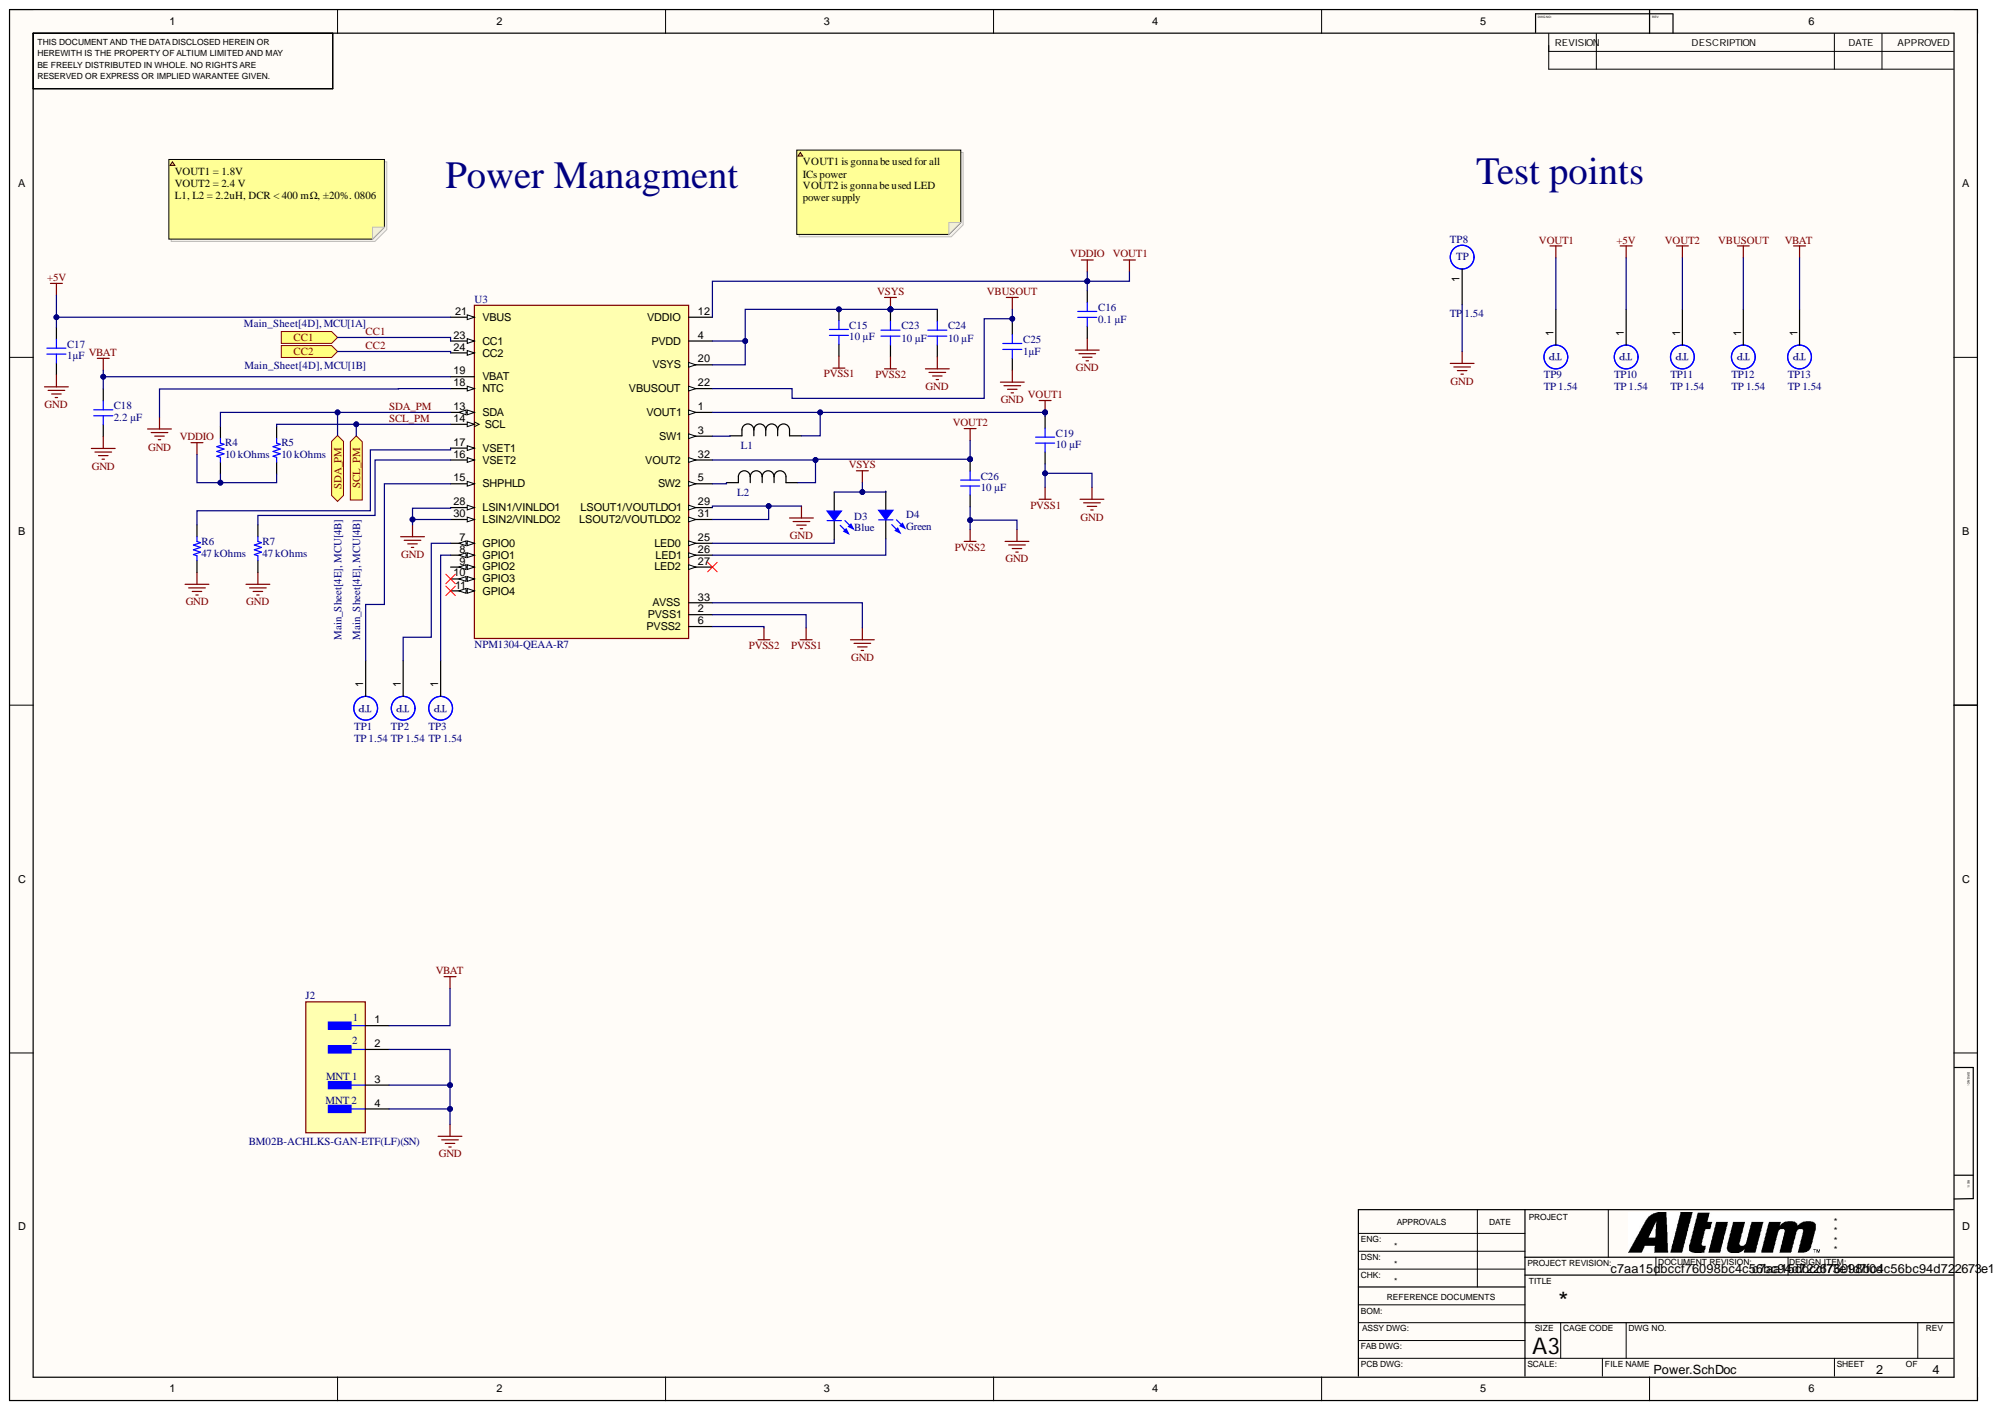
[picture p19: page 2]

THIS DOCUM ENT AND THE DATA DISCLOS ED HEREIN OR HERE WITH IS THE PROP ERT Y OF A LTIUM LIMIT ED AND M AY B E FRE E LY DIS TRIBUT ED IN WHOL E. NO RIGHT S ARE RE S ERV ED OR E X PRE S S OR IM P LIED W ARANT E E GIV EN. ±20%. 0806 | Power Managment V OUT1 is gon na be used for all ICs power VOUT2 is gon na be used LED power suppl y | R E V I S I O | N D E S C R I P T I O N | D A T E | A P P R O V E D

SDA_P M

VDDI | SCL_P M | 3 | VOUT

BM02B-ACHLKS-GAN-ETF(LF)

A P PROV A L S | DAT E | PROJECT | ****

ENG:
** DSN: | | PROJECT RE VISION: c 7 a a 1 5 | DOCUM ENT RE VISION: d b c cf7 6 0 9 8 b c 4 c 5c67baca9145dd7b2c2c6f7 | DE SIGN IT E M : 36e019d87bf 0c d4 c 5 6 b c 9 4 d 7 2
CHK : | | TIT L E *

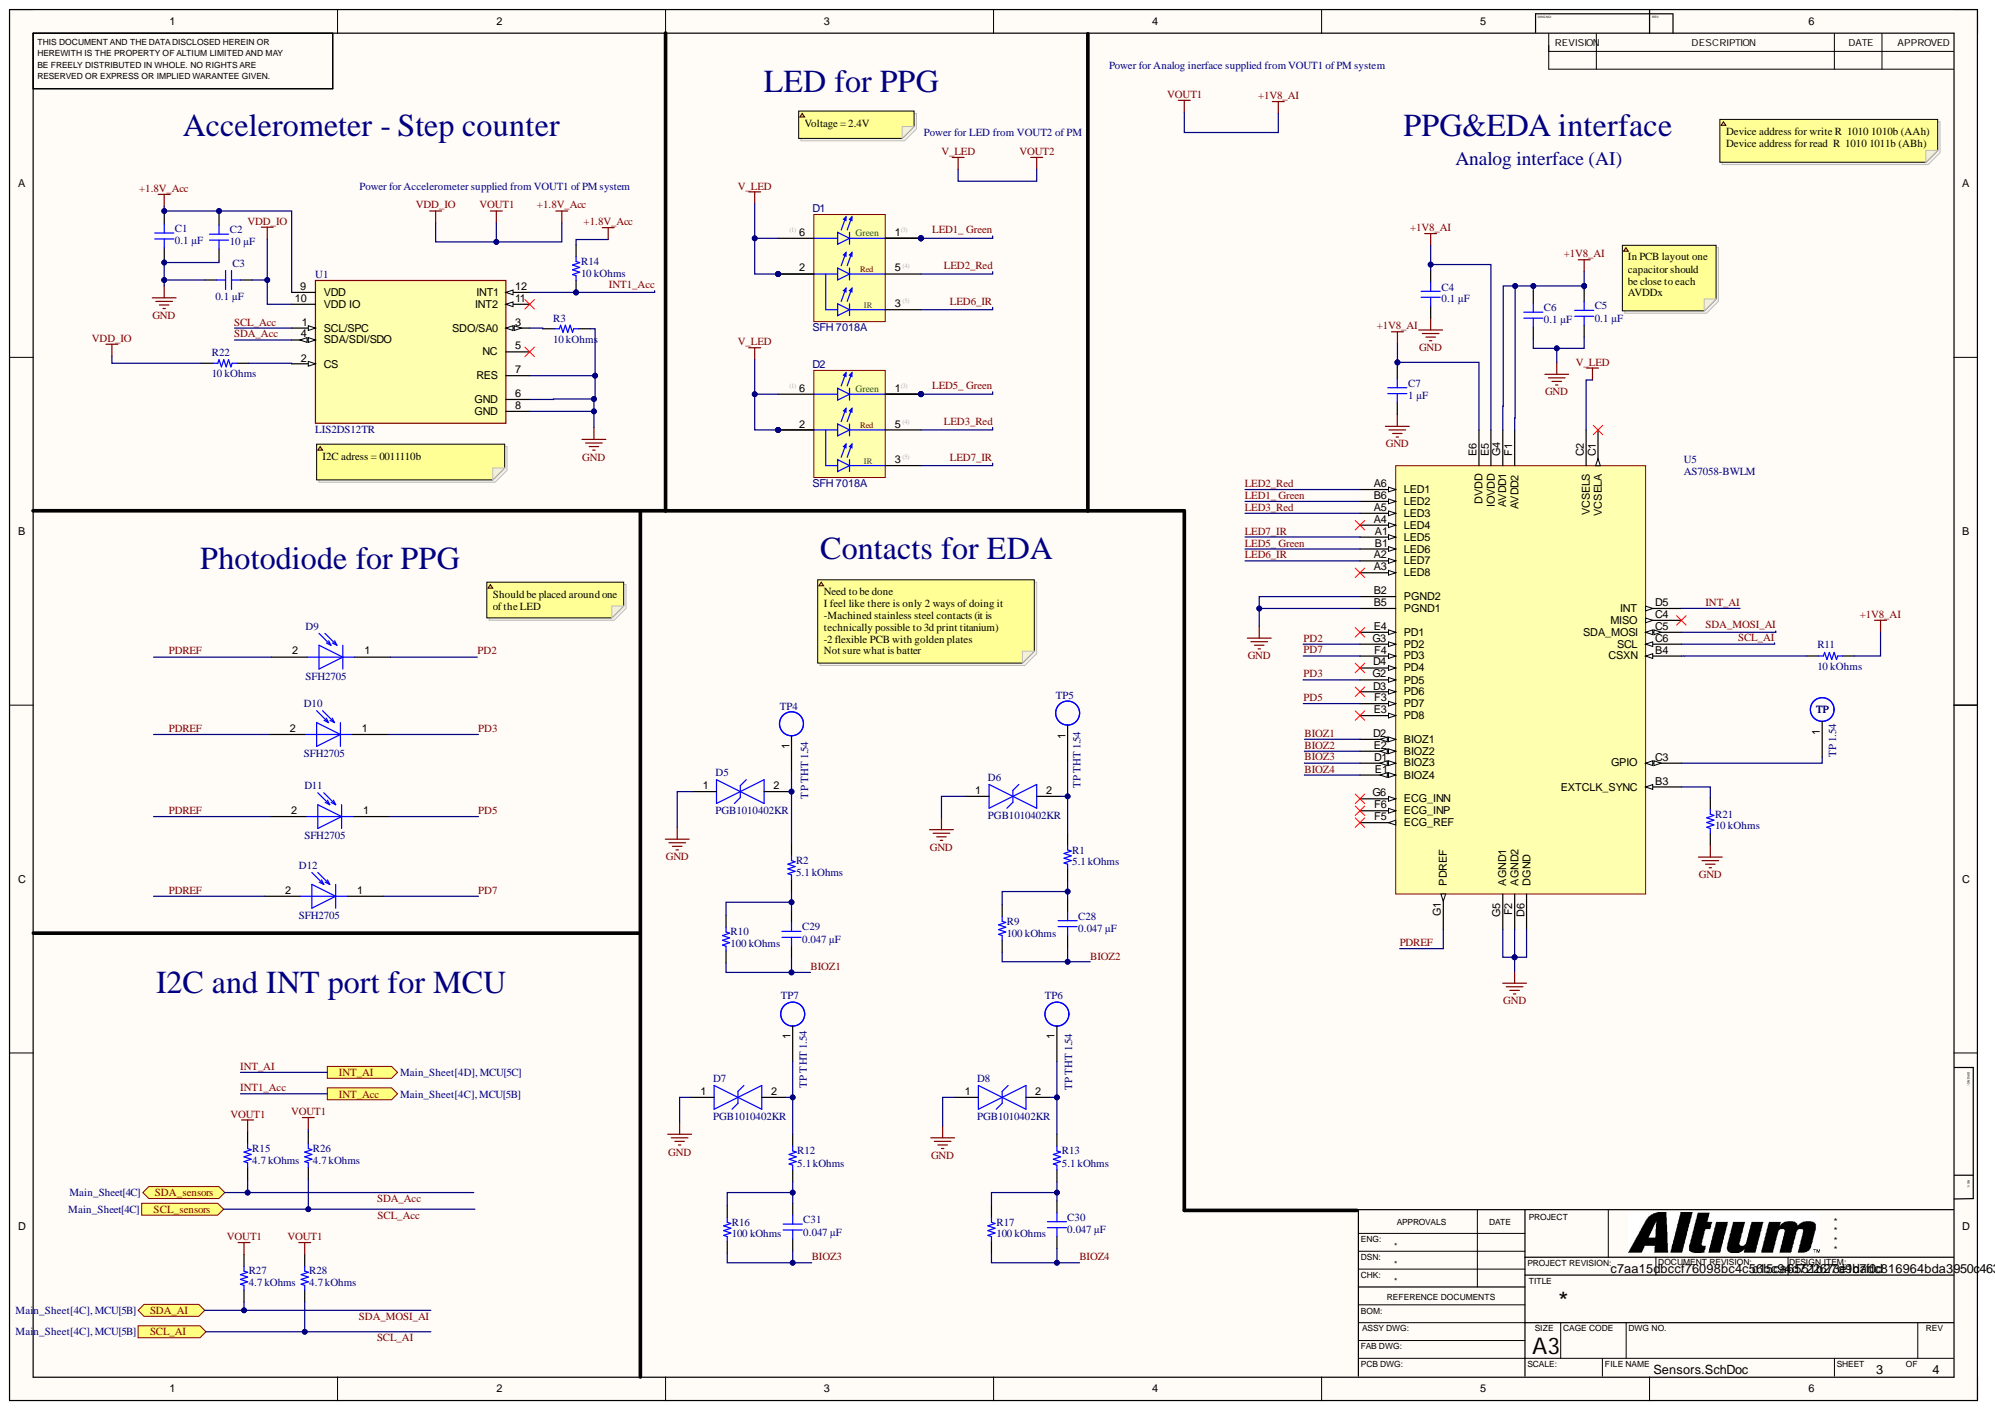
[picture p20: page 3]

THIS DOCUM ENT AND THE DATA DISCLOS ED HEREIN OR HERE WITH IS THE PROP ERT Y OF A LTIUM LIMIT ED AND M AY B E FRE E LY DIS TRIBUT ED IN WHOL E. NO RIGHT S ARE RE S ERV ED OR E X PRE S S OR IM P LIED W ARANT E E GIV EN. | -Step counter Power for Accelerometer supplied from VOUT1 of PM syst | LED for P P G Voltage = 2.4V Power for LED from VOUT2 of PM V_LE D VOUT V_LE D | VOUT 1 +1V8_A Analog inter +1V8_A I | R E V I S I O | N D E S C R I P T I O N | D A T E | A P P R O V E D

Power for Analog inerface supplied from VOUT1 of PM system

Device address for write R 1010 1010b (AAh
Device address for read R 1010 1011b (ABh

Need
I feel like
-Machined stainless steel con
tech
-2 flexible PCB wit

here is only 2 ways of doing it

Should be placed arou

Notsure what is batter

I2C and INT port for MCU

ENG:
** DSN: | PROJECT RE VISION: c 7 a a 1 5 | DOCUM ENT RE VISION: d b c cf7 6 0 9 8 b c 4 c 5c61 b5cc9a46d575212b62773de91 | DE SIGN IT E M : bd 7afd0cd8 1 6 9 6 4 b d a 3
CHK : | TIT L E *

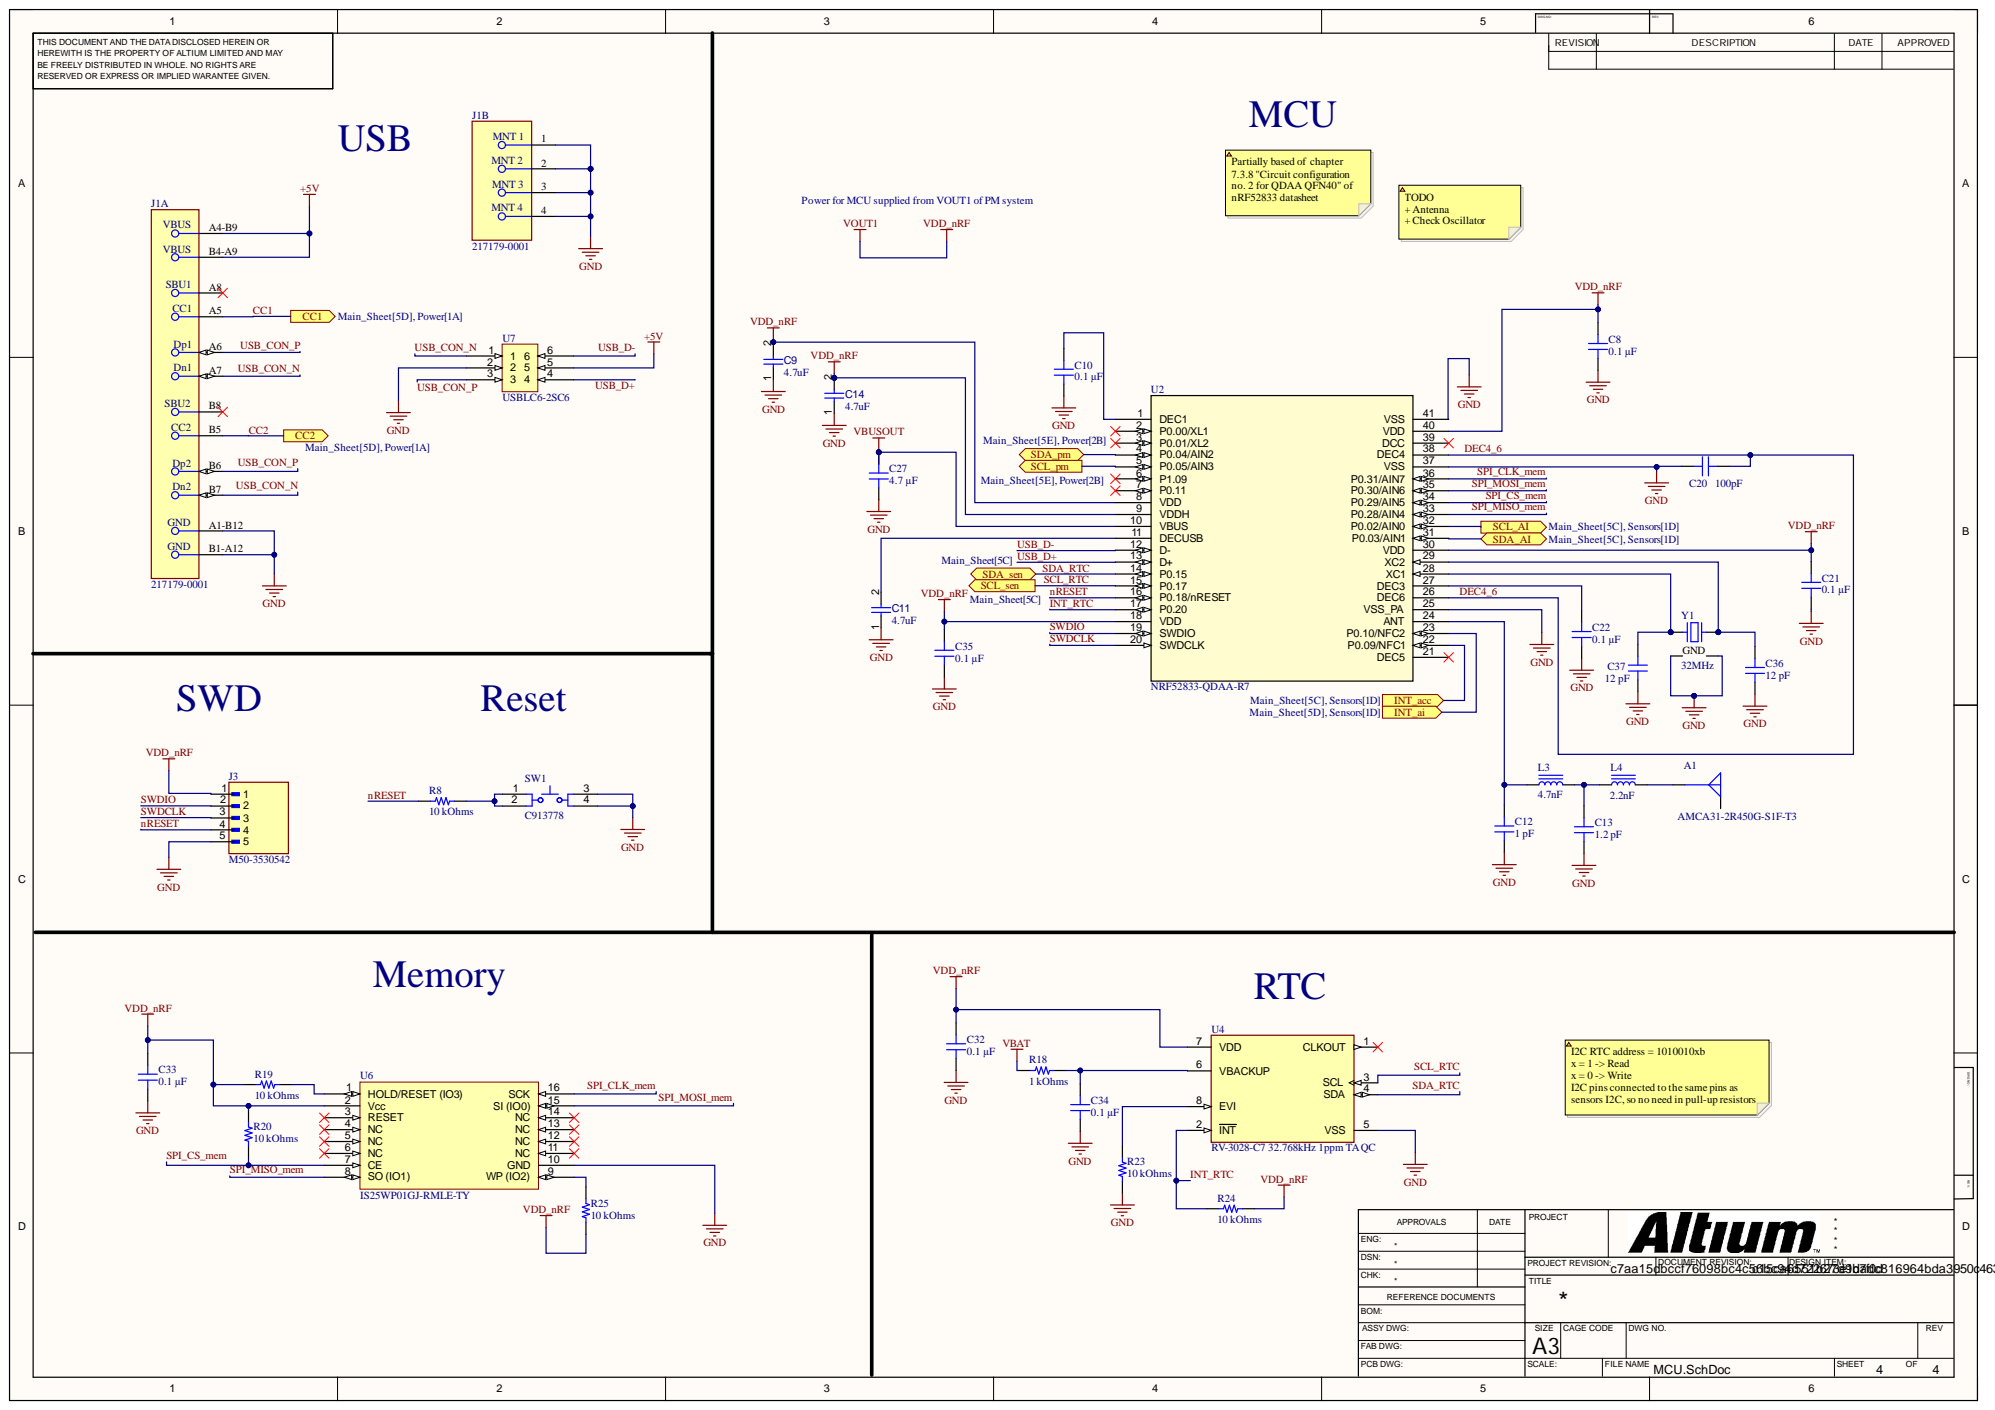
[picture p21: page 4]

DWG NO: | REV:

THIS DOCUMENT AND THE DATA DISCLOSED HEREIN OR HEREWITH IS THE PROPERTY OF ALTIUM LIMITED AND MAY BE FREELY DISTRIBUTED IN WHOLE. NO RIGHTS ARE RESERVED OR EXPRESS OR IMPLIED WARANTEE GIVEN. | J1B | MCU Partially based of chapter 7.3.8 "Circuit configuration no. 2 for QDAA QFN40" of nRF52833 datasheet TODO Power for MCU supplied from VOUT1 of PM system + Antenna + Check Oscillator VOUT1 VDD_nRF | REVISION | DESCRIPTION | DATE | APPROVED

VBUSOUT

P0.01/XL2 3 | DEC4_6

SDA_pm C27 SCL_pm 4.7 µF Main_Sheet[5E], Power[2B] | | P0.05/AIN3 5 | | VDD_nRF

P0.11 7 | SPI_MOSI_mem
VDD 8 | SPI_CS_mem GND
VDDH 9 | SPI_MISO_mem

I2C RTC address = 1010010xb
x = 1 -> Read
x = 0 -> Write
I2C pins connected to the same pins as
sensors I2C,so no need in pull-up resistors

DATE | PROJECT | * * APPROVALS * *

ENG: *
CHK: * | | TITLE *

DSN: *

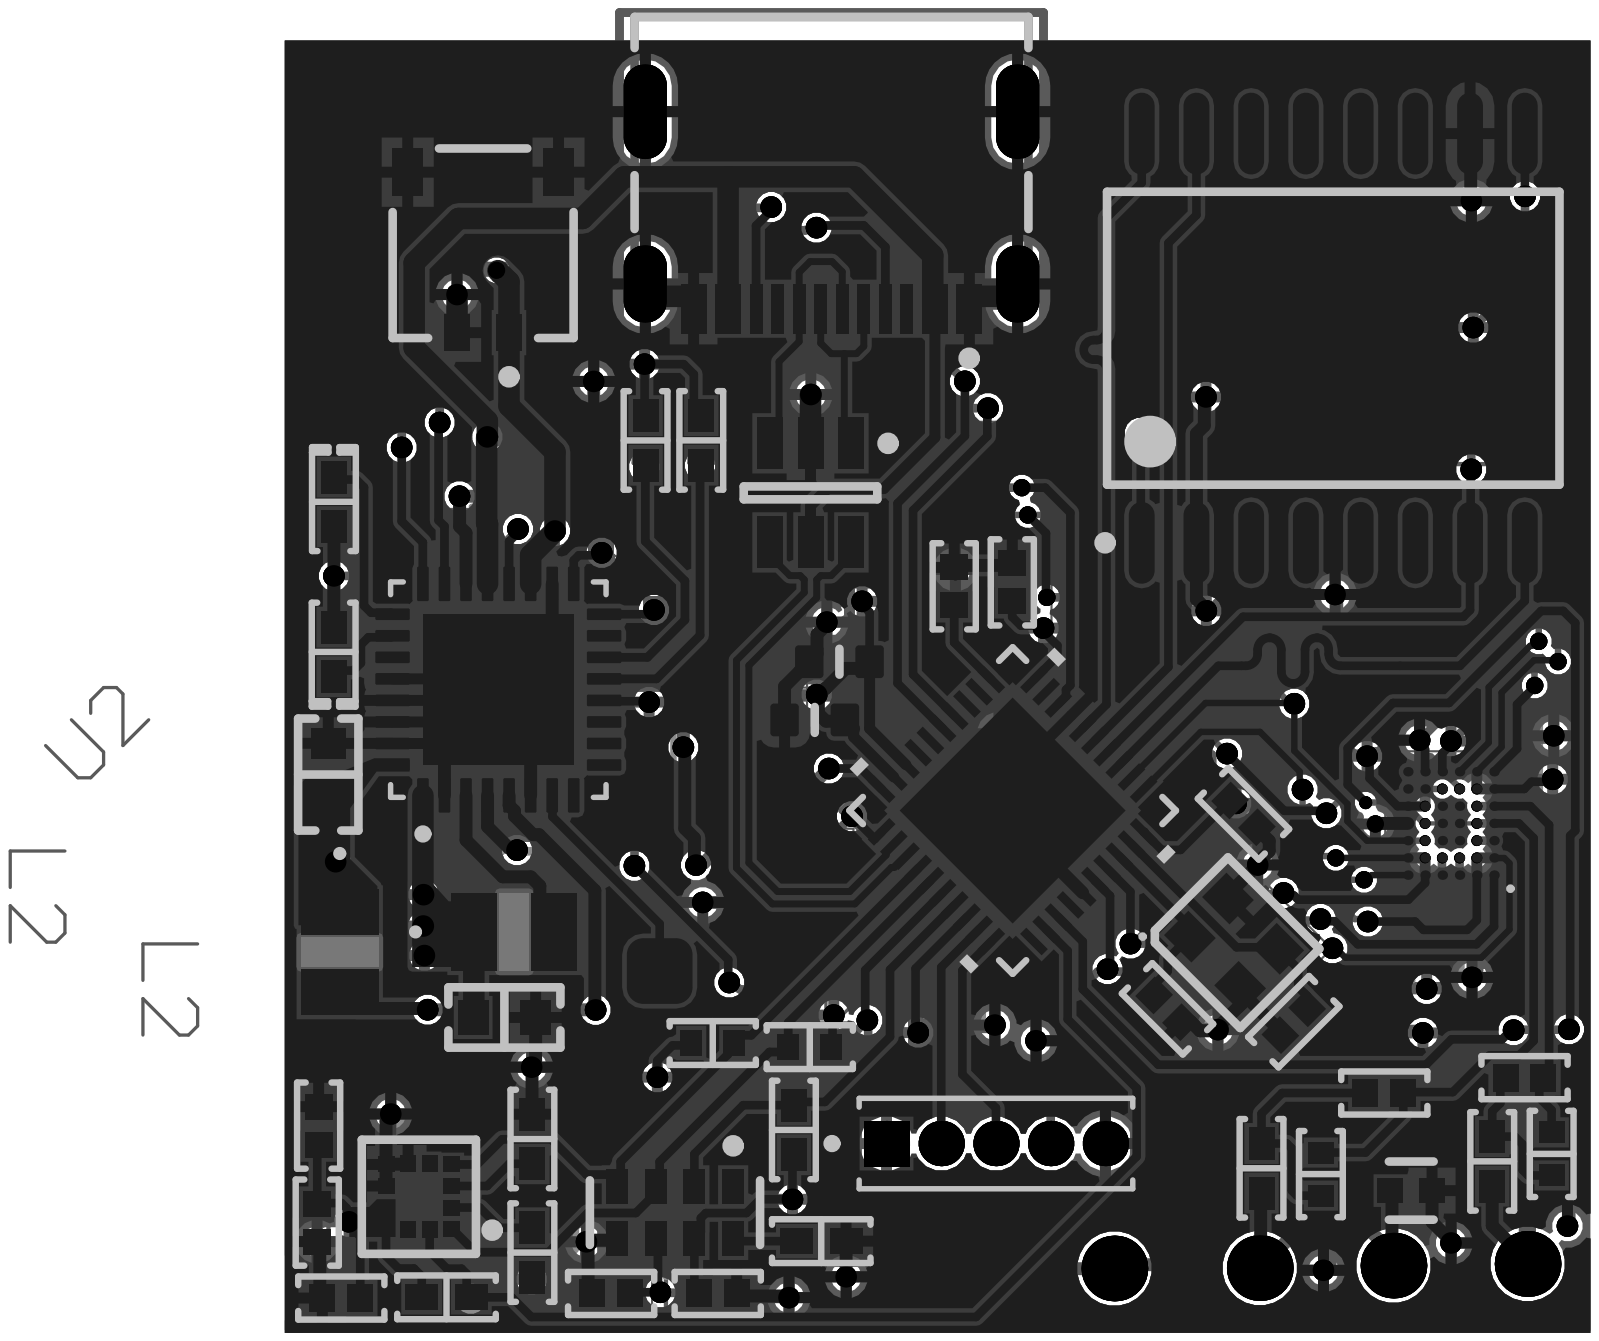
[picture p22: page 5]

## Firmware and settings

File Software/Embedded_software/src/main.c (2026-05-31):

/*
 * Copyright (c) 2012-2014 Wind River Systems, Inc.
 *
 * SPDX-License-Identifier: Apache-2.0
 */

#include <stdio.h>
#include <zephyr/kernel.h>
#include <zephyr/sys/printk.h>
#include <zephyr/drivers/sensor.h>
#include <zephyr/logging/log.h>
#include <zephyr/logging/log_ctrl.h> /* add this for LOG_PANIC */

#include <zephyr/drivers/rtc.h>
#include <zephyr/drivers/i2c.h>
#include <zephyr/drivers/flash.h>
#include <zephyr/drivers/gpio.h>
#include <zephyr/drivers/uart.h>
#include <zephyr/pm/device.h>
#include <zephyr/sys/poweroff.h>

#include <zephyr/sys/util.h>
#include <zephyr/fs/fs.h>
#include <zephyr/fs/littlefs.h>
#include <zephyr/storage/flash_map.h>
#include <zephyr/sys/timeutil.h>

// USB includes
#include <zephyr/usb/usb_device.h>
#include <zephyr/sys/ring_buffer.h>
#include <zephyr/usb/usbd.h>
#include <sample_usbd.h>

// Shell includes
#include <zephyr/shell/shell.h>
#include <zephyr/shell/shell_uart.h>   /* shell_backend_uart_get_ptr() */

#include "as7058_typedefs.h"
#include "as7058_drv.h"
#include "flash_drv.h"
#include "usb_drv.h"

LOG_MODULE_REGISTER(main, LOG_LEVEL_DBG);

/*
 *      DEFINITIONS
 */

// Flags
bool usb_connected = false;
bool usb_initalised = false;
bool shell_initialised = false;
bool flash_mounted = false;
bool rtc_initialised = false;
bool imu_initialised = false;
bool as7058_started = false;
bool measurments_en = true;

// Shell definitions
const struct device *i2c_dev;
const struct device *cdc_dev_usb;

// Flash
#define FLASH_NODE DT_NODE_BY_FIXED_PARTITION_LABEL(DT_N_NODELABEL_is25wp01g)
#define SPI_NODE DT_BUS(DT_PARENT(FLASH_NODE))

// AS7058 setup
#define I2C1_NODE DT_NODELABEL(as7058)
#define LIS2DS12_NODE DT_NODELABEL(lis2ds12)  

// DEVICES initialisation
const struct i2c_dt_spec dev_i2c = I2C_DT_SPEC_GET(I2C1_NODE);
const struct device *dev_rtc = DEVICE_DT_GET_ANY(microcrystal_rv3028);
const struct device *flash_dev = DEVICE_DT_GET_ANY(jedec_spi_nor);
//const struct device *dev_imu = DEVICE_DT_GET_ANY(st_lis2ds12);
const struct i2c_dt_spec imu_i2c = I2C_DT_SPEC_GET(LIS2DS12_NODE);

// Data blocks structure
#define rC_fifo_amount 423

struct readingContainer
{
    time_t time_sec;
    struct as7058_fifo_t data[rC_fifo_amount];
    uint8_t flags;
    uint16_t steps;
}; // 1280 bytes container - multiple of 256

// Time structure
struct rtc_time set_time = {
    .tm_year = 126, /* years since 1900 */
    .tm_mon = 5,    /* 0-indexed, January = 0 */
    .tm_mday = 1,
    .tm_hour = 12,
    .tm_min = 0,
    .tm_sec = 0,
};

/*
 *      Functions
 */

// Function to initialise step counter on IMU
int IMU_step_count_init(void)
{
	uint8_t reg;

	if(i2c_reg_read_byte_dt(&imu_i2c, 0x3F, &reg) < 0) {
		LOG_ERR("Failed to read step counter mode");
		return -1;
	}

	LOG_INF("Current 0x3F register: %x", reg);
	reg |= 0x01; // Set bit 0 to enable step counter mode

	if(i2c_reg_write_byte_dt(&imu_i2c, 0x3F, reg) < 0) {
		LOG_ERR("Failed to set step counter mode");
		return -1;
	}

	// Reset the step counter to 0
	if(i2c_reg_read_byte_dt(&imu_i2c, 0x3A, &reg) < 0) {
		LOG_ERR("Failed to read step counter reset register");
		return -1;
	}

	LOG_INF("Current 0x3A register: %x", reg);
	reg |= 0x80;  // Set bit 7 to reset step counter

	if(i2c_reg_write_byte_dt(&imu_i2c, 0x3A, reg) < 0) {
		LOG_ERR("Failed to reset step counter");
		return -1;
	}

	k_msleep(10); // Wait for the reset to take effect

	if(i2c_reg_read_byte_dt(&imu_i2c, 0x3D, &reg) < 0) {
		LOG_ERR("Failed to read FUNC_CK_GATE register after reset");
		return -1;
	}

	reg &= 0x04; // Clear bit 7 to enable step counter output
	LOG_INF("Current 0x3D register: %x", reg);
	
	reg = reg>>2; // Shift right to get the step counter output value
	if(reg != 0) {
		LOG_ERR("Step counter reset not finished, RST_PEDO bit: %x", reg);
	}

	return 0;
}

// Set up time
int rtc_driver_set_time(const struct device *dev_rtc, const struct rtc_time *timeptr)
{

    int ret = rtc_set_time(dev_rtc, timeptr);
    if (ret < 0)
    {
        LOG_ERR("Failed to set RTC time: %d", ret);
        return ret;
    }
    LOG_INF("Time set successfully");
    return 0;
}

// Get current time
int rtc_driver_get_time(const struct device *dev_rtc)
{
    struct rtc_time now;

    int ret = rtc_get_time(dev_rtc, &now);
    if (ret < 0)
    {
        LOG_ERR("Failed to get RTC time: %d", ret);
        return ret;
    }

    LOG_INF("Current time: %04d-%02d-%02d %02d:%02d:%02d",
            now.tm_year + 1900,
            now.tm_mon + 1, /* back to 1-indexed for display */
            now.tm_mday,
            now.tm_hour,
            now.tm_min,
            now.tm_sec);

    return 0;
}

/*
 *      Threads setup
 */

// Thread for saving measurments from as7058
static const struct gpio_dt_spec as7058_irq = GPIO_DT_SPEC_GET(DT_PATH(zephyr_user), ppg_irq_gpios);
static struct gpio_callback as7058_irq_cb;

// Struct for holding the workqueue
static struct k_work as7058_work;

#define WORK_STACK_SIZE 8192
#define WORK_PRIORITY 5

/* Actual processing — runs in work queue thread, not ISR context */
static void as7058_work_handler(struct k_work *work)
{
    ARG_UNUSED(work);

    int ret;
    uint16_t fifo_data_size = 0;
    static struct readingContainer rC;
    uint8_t step_count_h, step_count_l;

    rtc_get_time(dev_rtc, &set_time);
    rC.time_sec = timeutil_timegm(rtc_time_to_tm(&set_time)); //current time in seconds
	rC.steps = 0; //placeholder for step count, can be updated with actual logic
	rC.flags = 0; //placeholder for any flags, can be updated with actual logic

    ret = as7058_fifo_read_level(&dev_i2c, &fifo_data_size);
    if (ret < 0) {
        LOG_ERR("Failed to read FIFO level: %d", ret);
    } else {
        LOG_INF("FIFO level: %u samples", fifo_data_size);
    }

    for (int i = 0; i < fifo_data_size; i++) {
        ret = as7058_read_fifo_raw(&dev_i2c, (uint8_t *)&rC.data[i]);
        if (ret < 0) {
            LOG_ERR("Failed to read FIFO sample: %d", ret);
        }
    }

    if(i2c_reg_read_byte_dt(&imu_i2c, 0x3B, &step_count_l) < 0) {
		LOG_ERR("Failed to read step_count_l data");
	}
	if (i2c_reg_read_byte_dt(&imu_i2c, 0x3C, &step_count_h) < 0) {
		LOG_ERR("Failed to read step_count_h data");
	}

    rC.steps = (step_count_h << 8) | step_count_l;
	
    lfs_append_file("/lfs/readings.bin", &rC, sizeof(rC));

    /*
    
    TODO: Proper flash init
    
    */
}

static void gpio_isr(const struct device *dev, struct gpio_callback *cb, uint32_t pins)
{
    k_work_submit(&as7058_work);
}

// Shell init thread
struct k_work          shell_toggle_work;
static void shell_toggle_handler(struct k_work *work)
{
    ARG_UNUSED(work);
 
    const struct shell *sh = shell_backend_uart_get_ptr();
 
    if (!shell_initialised) {
        /* ── Enable ── */
        shell_start(sh);
        shell_initialised = true;
        LOG_INF("Shell ENABLED - use 'flash read' command to transmit readings");
    } else {
        /* ── Disable ── */
        shell_stop(sh);
        shell_initialised = false;
        LOG_INF("Shell DISABLED");
    }
}

// Data transmition thread
struct k_work   data_transmit_work;
static void data_transmit_handler(struct k_work *work)
{
    ARG_UNUSED(work);

    printk("Thread started\n");

    if(shell_initialised)
    {
        k_work_submit(&shell_toggle_work);
        k_msleep(100);
    }

    printk("Shell toggled\n");

    if (!host_ready) {
        LOG_WRN("Host not ready, cannot transmit");
        return;
    }

    LOG_INF("Starting data transmission...");

    int ret;
    static struct readingContainer onePack;
	struct fs_file_t file;
	struct fs_dirent entry;
	
	ret = fs_stat("/lfs/readings.bin", &entry);
	if (ret < 0) {
		LOG_ERR("Failed to stat file: %d", ret);
		return;
	}

	fs_file_t_init(&file);
	ret = fs_open(&file, "/lfs/readings.bin", FS_O_READ);
	if (ret < 0) {
		LOG_ERR("Failed to open /lfs/readings.bin: %d", ret);
		return;
	}

	LOG_INF("File opened, size: %zu bytes, %zu records", entry.size, entry.size / sizeof(onePack));

    char payload[1280];
	uint32_t records_sent = 0;
	uint32_t total_records = entry.size / sizeof(onePack);

	for (uint32_t i = 0; i < total_records; i++) {
	    ret = lfs_read_file_partial(&file, &onePack, sizeof(onePack));
		if (ret < 0) {
			LOG_ERR("Failed to read record %u: %d", i, ret);
			break;
		}
		
        memcpy(payload, &onePack, sizeof(payload));
		ret = enqueue_packet((uint8_t *)payload, (uint16_t)sizeof(payload), &cdc_dev_usb);
		if (ret < 0) {
            LOG_ERR("enqueue_packet failed for record %u: %d", i, ret);
			break;
    	}
		
		records_sent++;
        k_sleep(K_MSEC(5));
	}

    LOG_INF("Transmission complete: %u/%u records sent", records_sent, total_records);
    fs_close(&file);

    if(!shell_initialised)
    {
        k_work_submit(&shell_toggle_work);
        k_msleep(100);
    }
}

// System init function
static int system_init(void)
{
    int ret;

    // Step counter initilisation
    const struct device *dev_imu = DEVICE_DT_GET_ANY(st_lis2ds12);
	if (dev_imu == NULL || !device_is_ready(dev_imu)) {
        LOG_ERR("IMU Device not ready");
    }

    if (!device_is_ready(imu_i2c.bus)) {
		LOG_ERR("I2C bus %s is not ready!\n\r",imu_i2c.bus->name);
	}

    if(IMU_step_count_init() < 0) {
		LOG_ERR("Failed to initialize IMU step counter");
	}

    // Attaching work handlers   
    k_work_init(&as7058_work, as7058_work_handler);
    k_work_init(&shell_toggle_work, shell_toggle_handler);

    // Cheking if GPIO for interrupts is ready
    ret = gpio_is_ready_dt(&as7058_irq); 
    if (ret < 0) {
        LOG_ERR("init: GPIO device not ready");
        return -ENODEV;
    }

    // Configuring GPIO
    ret = gpio_pin_configure_dt(&as7058_irq, GPIO_INPUT);
    if (ret < 0) return ret;

    // Attaching interrupt to GPIO
    ret = gpio_pin_interrupt_configure_dt(&as7058_irq, GPIO_INT_EDGE_TO_INACTIVE);
    if (ret < 0) return ret;

    // Initialising callback for interrupt
    gpio_init_callback(&as7058_irq_cb, gpio_isr, BIT(as7058_irq.pin));
    ret = gpio_add_callback(as7058_irq.port, &as7058_irq_cb);
    if (ret < 0) return ret;

    // Checking if i2c node for as7058 intialised
    if (!device_is_ready(dev_i2c.bus)) {
        LOG_ERR("I2C bus not ready");
        return -1;
    }

    // Checking if falsh intialised
    if (!device_is_ready(flash_dev)) {
        LOG_ERR("Flash device not ready");
        return -1;
    }
    // Initialising file system
    uint8_t jedec_id[3];
	if (flash_read_jedec_id(flash_dev, (uint8_t *)jedec_id) < 0) {
		LOG_ERR("Failed to read JEDEC ID\n");
		return -1;
	}
	LOG_INF("Flash JEDEC ID: 0x%02X %02X %02X", jedec_id[0], jedec_id[1], jedec_id[2]);
	uint8_t fs_initialized = 0;
	if (init_fs() < 0) {
		LOG_ERR("Filesystem init failed");
		log_flush();
		return -1;
	}
	else {
		fs_initialized = 1;
	}

    // RTC initialising 
	if (dev_rtc == NULL || !device_is_ready(dev_rtc)) {
		LOG_ERR("RTC Device not ready");
	}

    // Setting time 
    rtc_driver_set_time(dev_rtc, &set_time); 
	int rc = lfs_read_file("/lfs/time.bin", &set_time, sizeof(set_time));
	if	( rc == sizeof(set_time)) {
		rtc_driver_set_time(dev_rtc, &set_time);
	}
	else{
		lfs_write_file("/lfs/time.bin", &set_time, sizeof(set_time));
		LOG_ERR("Failed to read time from file, using default error: %d", rc);
	}

    // Initialising AS7058
    ret = as7058_init(&dev_i2c);
    if (ret < 0) return ret;

    k_msleep(10);

    // Starting measurments
    ret = as7058_start(&dev_i2c);
    if (ret < 0) return ret;

    return 0;
}

// USB interrupt
static void usb_status_cb_2(enum usb_dc_status_code status, const uint8_t *param)
{
    switch (status) {
    case USB_DC_CONNECTED:
        /* Stop AS7058 measurements when USB connects */
        k_work_cancel_delayable(&as7058_work);
        as7058_stop(&dev_i2c);
        as7058_started = false;
        
        /* Enable shell for user interaction */
        if (!shell_initialised) {
            k_work_submit(&shell_toggle_work);
        }
        host_ready = true;
        LOG_INF("USB connected - measurements stopped, shell enabled");
        break;
        
    case USB_DC_DISCONNECTED:
        /* Disable shell and stop any pending operations */
        if (shell_initialised) {
            k_work_submit(&shell_toggle_work);
        }

        /* Resume AS7058 measurements */
        if(measurments_en)
        {
            as7058_start(&dev_i2c);
            as7058_started = true;  
        }
        host_ready = false;
        tx_busy    = false;
        LOG_INF("USB disconnected - shell disabled, measurements resumed");
        break;
        
    case USB_DC_CONFIGURED:
        LOG_INF("USB configured (enumeration complete)");
        break;
        
    case USB_DC_SUSPEND:
        LOG_INF("USB suspended");
        break;
        
    case USB_DC_RESUME:
        LOG_INF("USB resumed");
        break;
        
    default:
        break;
    }
}

static struct k_work_delayable line_ctrl_work;
 
static void line_ctrl_handler(struct k_work *work)
{
    check_line_ctrl(cdc_dev_usb);
    k_work_reschedule(&line_ctrl_work, K_MSEC(100));
}

int main(void)
{
    int ret;
    ret = system_init();
    if(ret<0){
        LOG_ERR("System init failed");
        return ret;
    }
    
    ret = usb_enable(usb_status_cb_2);
    if (ret != 0) {
        LOG_ERR("Failed to enable USB: %d", ret);
        return ret;
    }

     if (!device_is_ready(cdc_dev_usb)) {
        LOG_ERR("CDC-ACM device not ready after USB enable");
        return -ENODEV;
    }

    /* ── Wire up the IRQ handler from usb_drv.c ──────────────────── */
    uart_irq_callback_user_data_set(cdc_dev_usb, cdc_irq_handler, NULL);
    uart_irq_rx_enable(cdc_dev_usb);
 
    /* ── Start line-control polling (DTR detection) ──────────────── */
    k_work_init_delayable(&line_ctrl_work, line_ctrl_handler);
    k_work_reschedule(&line_ctrl_work, K_MSEC(100));

    LOG_INF("System ready - measuring continuously until USB connects");
    k_sleep(K_FOREVER);
    return 0;
}

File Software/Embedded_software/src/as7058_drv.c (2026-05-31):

#include <stdio.h>
#include <zephyr/kernel.h>
#include <zephyr/sys/printk.h>
#include <zephyr/drivers/sensor.h>
#include <zephyr/logging/log.h>
#include <zephyr/drivers/i2c.h>

#include "as7058_typedefs.h"
#include "as7058_drv.h"

LOG_MODULE_REGISTER(as7058, LOG_LEVEL_DBG);

/* User defined measurement variables */

// FIFO definitions
#define FIFO_MAX_LEVEL 511
#define FIFO_SAMPLE_COUNT 423 // Maaximum: 511

// PPG frequency and sample count
#define PPG_FREQ 10 // Hz

// ECG frequency
#define ECG_FREQ 10 // Hz

// PPG Modulator eneabling
#define PPG_MOD_1 1 // Enable Modulator1 0 = off, 1 = on
#define PPG_MOD_2 0 // Enable Modulator2 0 = off, 1 = on

// PPG LED current settings
#define PPG_LED_INIT (uint8_t)8 		// us; Max:255 - time before measurement for LED to reach stable brightness after being turned on
#define LED_1_max_current 1 // 0 = 25mA, 1 = 150mA, 2 = 225mA, 3 = 300mA (RED center)
#define LED_2_max_current 1 // 0 = 25mA, 1 = 150mA, 2 = 225mA, 3 = 300mA (GREEN center)
#define LED_3_max_current 0 // 0 = 25mA, 1 = 150mA, 2 = 225mA, 3 = 300mA
#define LED_4_max_current 0 // 0 = 25mA, 1 = 150mA, 2 = 225mA, 3 = 300mA
#define LED_5_max_current 1 // 0 = 25mA, 1 = 150mA, 2 = 225mA, 3 = 300mA
#define LED_6_max_current 1 // 0 = 25mA, 1 = 150mA, 2 = 225mA, 3 = 300mA 
#define LED_7_max_current 0 // 0 = 25mA, 1 = 150mA, 2 = 225mA, 3 = 300mA (IR center)
#define LED_8_max_current 0 // 0 = 25mA, 1 = 150mA, 2 = 225mA, 3 = 300mA

#define LED_1_current 20 	// mA
#define LED_2_current 20 	// mA
#define LED_3_current 0 	// mA
#define LED_4_current 0 	// mA
#define LED_5_current 20     // mA
#define LED_6_current 0 	// mA
#define LED_7_current 0  	// mA 
#define LED_8_current 0 	// mA

// PPG slecting which LEDs are on for which measurements
/*
 * Explanation on how to set up register LED_SUBx
 *
 * Each register devided into two 4-bit fields: subx_drv1_sel (bits 0-3) and subx_drv2_sel (bits 4-7)
 * Only one LED can be selected from each driver for each sub sample, 
 * so only one bit can be set in each 4-bit field. 
 * 
 * subx_drv1_sel selects which LED from 1-4 where bit 0 corresponds to LED1 and bit 3 corresponds to LED4.
 * subx_drv2_sel selects which LED from 5-8 where bit 0 corresponds to LED5 and bit 3 corresponds to LED8.
 * 0: Disabled
 * 1: Enabled
*/
//On wwdevice PCB LED1 - IR_1, LED2 - green_1, LED3 - IR_2, LED5 - RED_2, LED6 - green_2, LED7 - RED_1
#define LED_SUB1 0b00000010 // LED_SUB1: Selecting: LED2 as the source for the first sub sample (sub1_drv1_sel=2)
#define LED_SUB2 0b00000001 // LED_SUB2: LEFT DEFAULT
#define LED_SUB3 0b00010000 // LED_SUB3: LEFT DEFAULT
#define LED_SUB4 0b00000000 // LED_SUB4: LEFT DEFAULT
#define LED_SUB5 0b00000000 // LED_SUB5: LEFT DEFAULT
#define LED_SUB6 0b00000000 // LED_SUB6: LEFT DEFAULT
#define LED_SUB7 0b00000000 // LED_SUB7: LEFT DEFAULT
#define LED_SUB8 0b00000000 // LED_SUB8: LEFT DEFAULT

// PPG slecting which Photo diodes (PD) are on for which measurements
/*
 * Explanation on how to set up register PPGx_PDSELx
 *
 * Each register devided consists of 8 bits, where each bit corresponds to one of the 8 photodiodes (PD) in the system.
 * Bit 0 corresponds to PD1 and bit 7 corresponds to PD8.
 * PPGx means to which PPG driver the PD selection applies, where x is 1 or 2.
 * 
 * 0: Disabled
 * 1: Enabled
*/

#define PPG1_PDSEL1 0b00000010 // PPG1_PDSEL1: Selecting: photodiode 2 for sub sample 1 (ppg1_pdsel_sub1=2)
#define PPG1_PDSEL2 0b00000001 // PPG1_PDSEL2: LEFT DEFAULT
#define PPG1_PDSEL3 0b00000001 // PPG1_PDSEL3: LEFT DEFAULT
#define PPG1_PDSEL4 0b00000000 // PPG1_PDSEL4: LEFT DEFAULT
#define PPG1_PDSEL5 0b00000000 // PPG1_PDSEL5: LEFT DEFAULT
#define PPG1_PDSEL6 0b00000000 // PPG1_PDSEL6: LEFT DEFAULT
#define PPG1_PDSEL7 0b00000000 // PPG1_PDSEL7: LEFT DEFAULT
#define PPG1_PDSEL8 0b00000000 // PPG1_PDSEL8: LEFT DEFAULT
#define PPG2_PDSEL1 0b00000000 // PPG2_PDSEL1: LEFT DEFAULT
#define PPG2_PDSEL2 0b00000000 // PPG2_PDSEL2: LEFT DEFAULT
#define PPG2_PDSEL3 0b00000000 // PPG2_PDSEL3: LEFT DEFAULT
#define PPG2_PDSEL4 0b00000000 // PPG2_PDSEL4: LEFT DEFAULT
#define PPG2_PDSEL5 0b00000000 // PPG2_PDSEL5: LEFT DEFAULT
#define PPG2_PDSEL6 0b00000000 // PPG2_PDSEL6: LEFT DEFAULT
#define PPG2_PDSEL7 0b00000000 // PPG2_PDSEL7: LEFT DEFAULT
#define PPG2_PDSEL8 0b00000000 // PPG2_PDSEL8: LEFT DEFAULT


/* Calculations for registers setup */

// Calculations for LED 1
#if defined(LED_1_current) && defined(LED_1_max_current)
	#if LED_1_max_current == 0
		#if LED_1_current >= 25
			#define LED1_ICTRL 255
		#elif LED_1_current <= 0
			#define LED1_ICTRL 0
		#else
			#define LED1_ICTRL (uint8_t)((LED_1_current * 255) / 25)
		#endif
	#elif LED_1_max_current == 1
		#if LED_1_current > 150
			#define LED1_ICTRL 255
		#elif LED_1_current <= 0
			#define LED1_ICTRL 0
		#else
			#define LED1_ICTRL (uint8_t)((LED_1_current * 255) / 150)
		#endif
	#elif LED_1_max_current == 2
		#if LED_1_current >= 225
			#define LED1_ICTRL 255
		#elif LED_1_current <= 0
			#define LED1_ICTRL 0
		#else
			#define LED1_ICTRL (uint8_t)((LED_1_current * 255) / 225)
		#endif
	#elif LED_1_max_current == 3
		#if LED_1_current >= 300
			#define LED1_ICTRL 255
		#elif LED_1_current <= 0	
			#define LED1_ICTRL 0
		#else
			#define LED1_ICTRL (uint8_t)((LED_1_current * 255) / 300)
		#endif
	#else
		#error "Invalid LED_1_max_current value, should be 0, 1, 2, or 3"
		#define LED1_ICTRL 0
	#endif
#endif

// Calculations for LED 2
#if defined(LED_2_current) && defined(LED_2_max_current)
	#if LED_2_max_current == 0
		#if LED_2_current > 25
			#define LED2_ICTRL 255
		#elif LED_2_current <= 0
			#define LED2_ICTRL 0
		#else
			#define LED2_ICTRL (uint8_t)((LED_2_current * 255) / 25)
		#endif
	#elif LED_2_max_current == 1
		#if LED_2_current > 150
			#define LED2_ICTRL 255
		#elif LED_2_current <= 0
			#define LED2_ICTRL 0
		#else
			#define LED2_ICTRL (uint8_t)((LED_2_current * 255) / 150)
		#endif
	#elif LED_2_max_current == 2
		#if LED_2_current > 225
			#define LED2_ICTRL 255
		#elif LED_2_current <= 0
			#define LED2_ICTRL 0
		#else
			#define LED2_ICTRL (uint8_t)((LED_2_current * 255) / 225)
		#endif
	#elif LED_2_max_current == 3
		#if LED_2_current > 300
			#define LED2_ICTRL 255
		#elif LED_2_current <= 0	
			#define LED2_ICTRL 0
		#else
			#define LED2_ICTRL (uint8_t)((LED_2_current * 255) / 300)
		#endif
	#else
		#error "Invalid LED_2_max_current value, should be 0, 1, 2, or 3"
		#define LED2_ICTRL 0
	#endif
#endif
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

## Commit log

2026-05-31 Source for wrist monitoring device, initial commit
    [BOM.csv, Case_Body.obj, Case_Body.stl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]
2026-05-31 Removed fixed Altium folder
    [MCU.SchDoc, Main_Sheet.SchDoc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]
2026-06-06 BOM in readme
2026-06-06 Flash in BOM fix
2026-06-06 Updated BOM and CPL files
    [BOM.csv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]
2026-06-06 Mechanical BOM and Tests section
2026-06-06 Ordering and assembly guide for hardware
    [Electrode.obj, Electrode.stl]
2026-06-06 image addded into full assembly section
